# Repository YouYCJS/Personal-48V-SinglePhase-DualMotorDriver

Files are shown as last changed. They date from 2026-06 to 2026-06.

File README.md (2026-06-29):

# 48V Dual Motor Driver System (V2)
**48V 듀얼 모터 드라이버 시스템 — 컨트롤 + 파워 보드**

> ⚠️ Private — 직무 프로젝트 기록용

> 48V 환경에서 로터·스테이터를 구동하는 듀얼 모터 드라이버 시스템.
> PC 통신·전원 분배를 담당하는 ESP32 컨트롤 보드와, 게이트 드라이버·MOSFET로
> 실제 전류를 구동하는 파워 보드로 구성됩니다. (V1 → V2 스펙업 설계)

## 시스템 구성
PC ──USB──▶ [ESP32 컨트롤 보드] ──제어·전원──▶ [파워 보드] ──▶ 모터 (로터/스테이터)
---

# 1. ESP32 컨트롤 보드

PC와 통신해 제어 파라미터를 주고받고, 파워 보드로 제어 신호와 전원을 분배.

- **PC 인터페이스**: USB로 파라미터 입출력
- **전원 관리**: 12V → LM2596으로 5V 스텝다운, ESP32 공급
- **전원 분배**: 파워 보드로 12V / 3.3V 공급 (A89500 · ACS37220용)
- **전원 충돌 방지**: USB·외부전원 동시 인가 시 ESP32 손상 → 몰렉스 스위치로 전원 소스 택일

| 앞면 | 뒷면 |
|:---:|:---:|
| ESP32 보드 앞면 | ESP32 보드 뒷면 |

| 스키매틱 | PCB |
|:---:|:---:|
| ESP32 스키매틱 | ESP32 레이아웃 |

---

# 2. 파워 보드 (모터 컨트롤)

게이트 드라이버 + MOSFET로 실제 모터 전류를 구동. A/B상 풀브리지로 양방향 구동·전류 센싱.

### 구성
- **게이트 드라이버**: A89500 ×4
- **파워 MOSFET**: IRFB4115 ×8 (풀브리지)
- **전류 센서**: ACS37220 ×2 (위상별)
- **출력**: XT90 (A+/A-/B+/B-), 벌크 커패시터
- **기판**: 4-layer PCB

### 부품 선정 근거

V4 모터의 권선 저항(0.5~0.6Ω) 기준, 48V 구동 시 기동·인러시 구간에서 80~100A가 요구됨.
정상 운전 시 BEMF로 실 전류는 낮아지나, 최악 조건 대응을 위해 V1 대비 주요 부품을 스펙업.

**게이트 드라이버 — A89500 (Allegro)**
- 하프브리지 통합(HS+LS) + 부트스트랩 내장 → N채널만으로 H-브리지 구성
- 슛스루 방지 + 슈미트 트리거 입력 내장 → 기존 로직 게이트(SN74HCS14) 제거, BOM 간소화
- RESETn(FAULT)로 비상 정지 / 3.3V 로직 → ESP32-S3 직결
- *기존 1EDN8550(싱글 로우사이드, 하이사이드 외부회로 필요) 대비 통합도↑ 부품수↓ 안전성↑*

**파워 MOSFET — IRFB4115**

| 항목 | 기존 IRFZ44N | 신규 IRFB4115 |
|---|---|---|
| VDSS | 55V | **150V** (48V 대비 3배 마진) |
| ID | 49A | **104A** |
| RDS(on) | 17.5mΩ | **9.3mΩ** |
| Qg | 67nC | **150nC** |

- IRFZ44N은 내압 마진 1.15배뿐 → 역기전력 시 위험으로 48V 부적합
- IRFB4115로 마진 확보 + 저발열, 빠른 스위칭(A89500 조합)

**전류 센서 — ACS37220**

| 항목 | 기존 ACS712 | 신규 ACS37220 | 효과 |
|---|---|---|---|
| 측정 범위 | 최대 30A | **±150A** | 80~100A 측정 가능 |
| 발열(100A) | 12W | **1W** | 약 1/12 |
| ESP32 연결 | 5V→분압 필요 | **3.3V 직결** | 회로 간소화 |
| 과전류 보호 | SW(느림) | **HW FAULT 3µs** | 즉각 보호 |
| 응답 속도 | 80kHz | **150kHz** | PWM 측정 정확도↑ |

- ACS712는 80~100A 측정 자체 불가 → ACS37220으로 범위·발열·보호 모두 개선

### 설계 포인트
- **레이어 수 결정**: 6-layer 검토했으나 구조상 4-layer로 충분하다 판단 → 과설계·비용 배제
- **신호-전력 물리 분리**: 신호선을 PCB 트레이스로 라우팅하지 않고 점퍼선(하네스)으로
  컨트롤 보드-칩 직접 연결 → 파워부 노이즈 유입 물리적 차단, 디버깅·교체 유연성 확보
- **EMI 최소화**: 신호선이 파워 MOSFET부와 닿지 않도록 배선 최소화 + GND 가드링

### 완성된 보드

| 앞면 | 뒷면 |
|:---:|:---:|
| 파워 보드 앞면 | 파워 보드 뒷면 |

### 회로 설계
파워 보드 스키매틱

### PCB 레이아웃 (4-Layer)

| Layer 1 (Top) | Layer 2 |
|:---:|:---:|
| Layer 1 Top | Layer 2 |

| Layer 3 | Layer 4 (Bottom) |
|:---:|:---:|
| Layer 3 | Layer 4 Bottom |

---

## 설계 회고
- V1(BTS7960, 12V) → V2(A89500 + IRFB4115 + ACS37220, 48V) 스펙업 설계
- 부품 선정을 마진·발열·보호·통합도 기준으로 비교 검토 후 결정
- 제어(MCU)와 구동(파워)을 분리한 2-보드 시스템 아키텍처
- 고전류 환경의 노이즈를 4층 구조 + 하네스 분리 + GND 가드링으로 관리

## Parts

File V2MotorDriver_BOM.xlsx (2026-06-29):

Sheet: RotorStator_Control_Board(보드1개분
No, | 부품기호 | 갯수 | 값 | FOOTPRINT | 설명 | 공급처 | 단가 | 링크
1 | J1,J2,J5 | 3 | XT90PW-M | AMASS_XT90PW-M | 전원 커넥터, XT90PW 수, 2핀, 45A(연속)/피크90A, 500V, THT 수평실장 | 엘레파츠 | 1540 | https://www.eleparts.co.kr/goods/view?no=12773229
2 | D1 | 1 | SS54-HF | DIOM5025X220N | Diode, Schottky, 40V, 5A, SMA (DO-214AC) | 디바이스마트 | 1331 | https://www.devicemart.co.kr/goods/view?no=15948320
3 | D2 | 1 | SMCJ58A | DIOM7959X262N | TVS Diode, Unidirectional, 58V Standoff, 93.6V Clamp, 1500W, SMC (DO-214AB) | 디바이스마트 | 1331 | https://www.devicemart.co.kr/goods/view?no=15930384
4 | R1,R3,R4,R5,R7,R8 | 6 | 10K | RES0805W | ChipResistor, SMD, F급, (±1%), 10K옴, 2012, 1/8W | 디바이스마트 | 5.5 | https://www.devicemart.co.kr/goods/view?no=1376585
5 | R2,R6 | 2 | 66.5K | RES0805W | ChipResistor / SMD / F급 / (±1%) / 66.5K옴 / 2012 사이즈 / 1릴 : 5000개 | 디바이스마트 | 2.97 | https://www.devicemart.co.kr/goods/view?no=26630
6 | C1,C4 | 2 | 470uF | CAPAE1900X2200N | 470uF ±20% 100V Aluminum Electrolytic Capacitors 5000hrs@105℃ | 디바이스마트 | 12221 | https://www.devicemart.co.kr/goods/view?no=16012986
7 | M1,M2,M3,M4, M5,M6,M7,M8 | 8 | IRFB4115 | IRFB4115 | INFINEON - IRFB4115PBF - Power MOSFET, N Channel, 150 V, 104 A, 0.011 ohm, TO-220AB, Through Hol | 디바이스마트 | 6127 | https://www.devicemart.co.kr/goods/view?no=14931375
8 | C2,C5,C6,C9,C11,C14,C16,C17,C20,C22 | 10 | 100nF(=0.1uF) | CAP0805R | 2012 / 100nF / 50V / K급 / SMD세라믹캐패시터 | 디바이스마트 | 44 | https://www.devicemart.co.kr/goods/view?no=8191
9 | C3,C10,C15,C21 | 4 | 1uF | CAP0805R | 사이즈 : 2012 / 전압 : 50Vdc / 용량 : 1uF / 오차 : ±10 % / 온도특성 : X7R | 디바이스마트 | 88 | https://www.devicemart.co.kr/goods/view?no=14913274
10 | C7,C12,C18,C23 | 4 | 10uF | CAP0805R | 사이즈 : 2012 / 전압 : 25Vdc / 용량 : 10uF / 오차 : ±10 % / 온도특성 : X5R | 디바이스마트 | 88 | https://www.devicemart.co.kr/goods/view?no=14913258
11 | C8,C13,C19,C24 | 4 | 470nF(=0.47uF) | CAP0805R | 2012 / 470nF / 50V / K급 / SMD세라믹캐패시터 | 디바이스마트 | 17.6 | https://www.devicemart.co.kr/goods/view?no=1382403
12 | FL1,FL2 | 2 | BLM18AG601SN1D | BEADC1608X95N | 페라이트 비드 600 OHM 25% Alternate Sizing Guide Below / Mouser Part Number : 81-BLM11A601S | 디바이스마트 | 187 | https://www.devicemart.co.kr/goods/view?no=15405006
13 | J3 | 1 | S10B-XH-A | JST_B10B-XH-A | Connector Header Through Hole, Right Angle 10 position 0.098" (2.50mm) / Digi-Key Part Number : 455-S10B-XH-A-ND | 디바이스마트 | 990 | https://www.devicemart.co.kr/goods/view?no=15442721
14 | A1,A2 | 2 | ACS37220LEZATR-150B3 ACS37220LEZATR-100B3 | ACS37220 | Current Sensor, Hall-Effect, ±150A, Bidirectional, 3.3V, Analog Out, QFN-7 (4x4mm) Current Sensor, Hall-Effect, ±100A, Bidirectional, 3.3V, Analog Out, QFN-7 (4x4mm) | 디바이스마트 | 5269 | https://www.devicemart.co.kr/goods/view?no=16042461
15 | U1,U2,U3,U4 | 4 | A89500GEJTR-T | A89500GEJTR-T | Gate Driver, Half-Bridge, 100V, N-Ch MOSFET, Bootstrap, 8-15V VCC, DFN-10 | 디바이스마트 | 3003 | https://www.devicemart.co.kr/goods/view?no=16042465
16 | J4 | 1 | 35318-0420 | MOLEX_353180420 | Connector, Header, Mini-Fit Jr, 4.2mm, 2x2, 4-Circuit, Right-Angle, 6A, THT | 디바이스마트 | 814 | https://www.devicemart.co.kr/goods/view?no=16042466

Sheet: ESPBoard
No, | 부품기호 | 갯수 | 값 | FOOTPRINT | 설명 | 공급처 | 단가 | 링크
1 | C2 | 1 | 100uF | 100uF | [SAMYOUNG] SMD E/C 35V 100uF (105℃)/6.3 Ø x8mm | 디바이스마트 | 220 | https://www.devicemart.co.kr/goods/view?no=30362
2 | DG5,DG6 | 2 | 141V (6핀) | 141V-6P | 핀간격 2.54mm / 전압 150V / 전류 2A / AWG : 26~20 | 디바이스마트 | 1243 | https://www.devicemart.co.kr/goods/view?no=23323
3 | DG2,DG3 | 2 | 141V (12핀) | 141V-12P | 핀간격 2.54mm / 전압 150V / 전류 2A / AWG : 26~20 | 디바이스마트 | 2475 | https://www.devicemart.co.kr/goods/view?no=23317
4 | DG1 | 1 | 141V (20핀) | 141V-20P | 핀간격 2.54mm / 전압 150V / 전류 2A / AWG : 26~20 | 디바이스마트 | 4125 | https://www.devicemart.co.kr/goods/view?no=23309
5 | C1 | 1 | 220uF | 220uF | [SAMYOUNG] SMD E/C 35V 220uF (85℃)/8Ø x10mm | 디바이스마트 | 198 | https://www.devicemart.co.kr/goods/view?no=1245625
6 | J1,J5 | 2 | 39288040 | 5566-02_MOL | 5557 커넥터에 사용 / 스트레이트 타입 / 4.2mm 피치 / 2pin | 디바이스마트 | 319 | https://www.devicemart.co.kr/goods/view?no=348
7 | J2,J6 | 2 | 39288040 | 5566-04_MOL | 5557 커넥터에 사용 / 스트레이트 타입 / 4.2mm 피치 / 4pin | 디바이스마트 | 385 | https://www.devicemart.co.kr/goods/view?no=349
8 | C3 | 1 | 100nF(=0.1uF) | CAP0805R | 2012 / 100nF / 50V / K급 / SMD세라믹캐패시터 | 디바이스마트 | 44 | https://www.devicemart.co.kr/goods/view?no=8191
9 | D1 | 1 | SS34 | DIOM7959X265N | SMD타입 3A/40V, 서지 100A (4.5X2.5) / SMA | 디바이스마트 | 110 | https://www.devicemart.co.kr/goods/view?no=11738
10 | U2 | 2 | ESP32-S3-WROOM2 | ESP32-S3-DEVKITC-1 | 핀헤더 소켓 / 스트레이트 타입 / DIP 타입 / 2.54mm pitch / 1열 / 40pin | 디바이스마트 | 583 | https://www.devicemart.co.kr/goods/view?no=3585
11 | J3,J4 | 2 | S10B-XH-A | JST_B10B-XH-A | Connector Header Through Hole, Right Angle 10 position 0.098" (2.50mm) / Digi-Key Part Number : 455-S10B-XH-A-ND | 디바이스마트 | 990 | https://www.devicemart.co.kr/goods/view?no=15442721
12 | R1 | 1 | 1K | RES0805W | ChipResistor / SMD / J급 / (±5%) / 1K옴 / 2012 | 디바이스마트 | 5.5 | https://www.devicemart.co.kr/goods/view?no=19277
13 | R2 | 1 | 3.3K | RES0805W | ChipResistor / SMD / B급 / (±0.1%) / 3.3K옴 / 2012 / HighPrecisionChipResistors / 1/10W / 온도계수(TCR=25ppm) | 디바이스마트 | 253 | https://www.devicemart.co.kr/goods/view?no=39586
14 | L1 | 1 | 33uH | SC1280S-33uH | 파워인덕터 / 용량값 : 33uH / 사이즈 : 12.2 X 12.2 X 8.0/ -20℃ ~85℃ | 디바이스마트 | 242 | https://www.devicemart.co.kr/goods/view?no=6615
15 | VR1 | 1 | LM2596S-5.0 | VREG_LM2596S-5.0/NOPB | Buck Switching Regulator IC Positive Fixed 5V 1 Output 3A TO-263-6, D2PAK (5 Leads + Tab), TO-263BA / Digi-Key Part Number : LM2596S-5.0/NOPB-ND | 디바이스마트 | 14982 | https://www.devicemart.co.kr/goods/view?no=12458270

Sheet: Sheet1
3 | 1485 | 4455 |  | 1 | 220 | 220
1 | 1331 | 1331 |  | 2 | 1243 | 2486
1 | 1331 | 1331 |  | 2 | 2475 | 4950
6 | 5.5 | 33 |  | 1 | 4125 | 4125
2 | 2.97 | 5.94 |  | 1 | 198 | 198
2 | 12221 | 24442 |  | 2 | 319 | 638
8 | 6127 | 49016 |  | 2 | 385 | 770
10 | 44 | 440 |  | 1 | 44 | 44
4 | 88 | 352 |  | 1 | 110 | 110
4 | 88 | 352 |  | 2 | 583 | 1166
4 | 17.6 | 70.4 |  | 2 | 990 | 1980
2 | 187 | 374 |  | 1 | 5.5 | 5.5
1 | 990 | 990 |  | 1 | 253 | 253
2 | 5269 | 10538 |  | 1 | 242 | 242
4 | 3003 | 12012 |  | 1 | 14982 | 14982
1 | 814 | 814 |  |  |  | 32169.5
 |  | 106556.34 |  |  |  |  | 02+
 |  |  | 852450.72 | 257356
 |  |  |  | 1269806.72

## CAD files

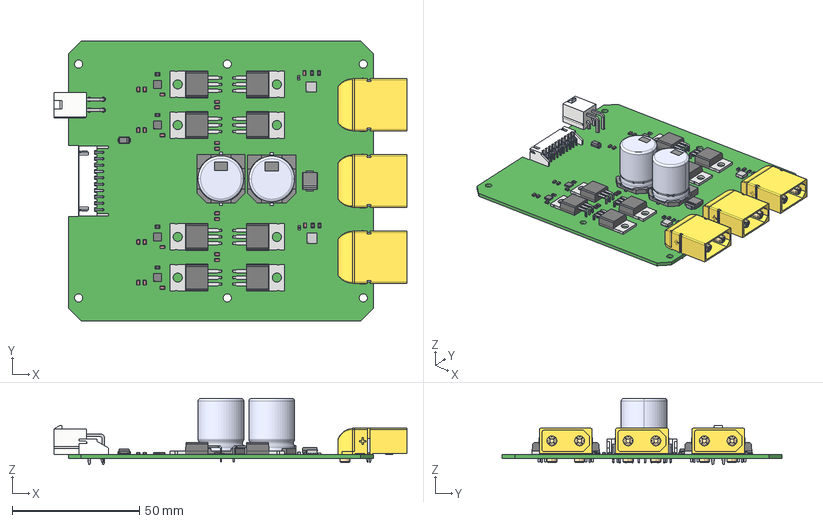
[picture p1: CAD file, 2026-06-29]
48V-MotorDriver-DualControlBRD/RotorStator_PowerControl.step
138.9 x 110.0 x 26.0 mm
FILTER_BLM18AG_MUR x 2
RES0805 x 8
TO-220_horizontal_line x 8
SxB-XH-A_10
pin^SxB-XH-A ass_bent x 2
pin^SxB-XH-A ass x 8
ACS37220 x 2

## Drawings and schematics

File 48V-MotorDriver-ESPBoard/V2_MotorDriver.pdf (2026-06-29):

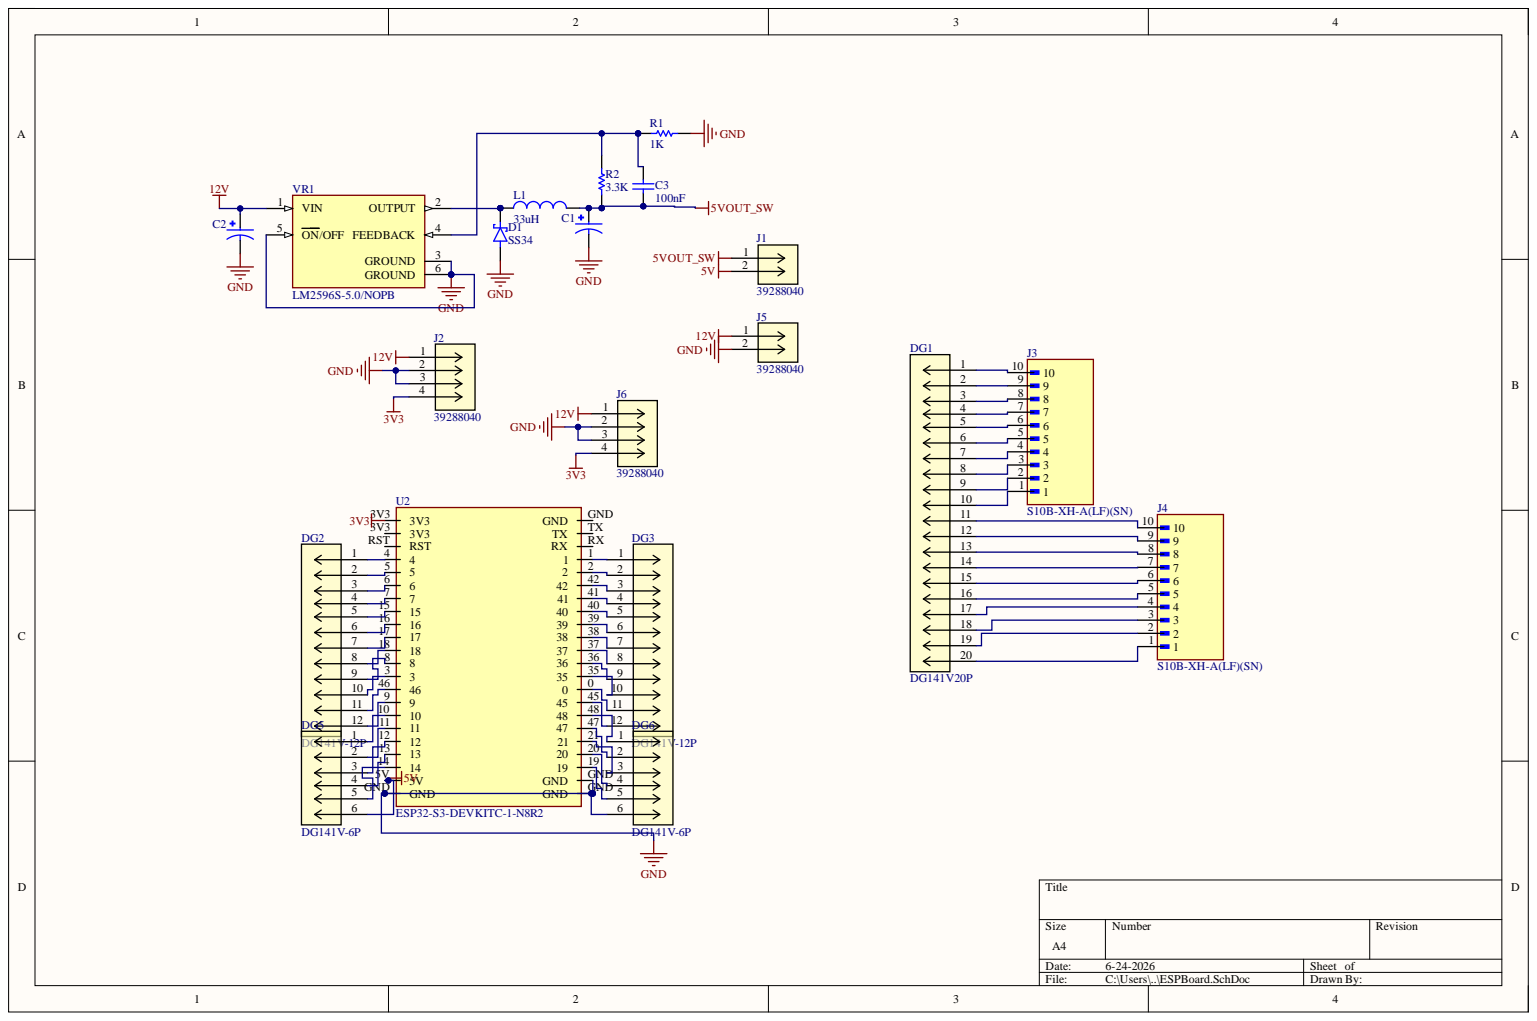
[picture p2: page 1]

RST RST 4 4 5 5 6 6 7 7 15 15 16 16 17 17 18 18 8 8 3 3 46 46 9 9 10 10 11 11 3V3 3V3 12 12 13 13 14 14 5V 5V GND GND

1 0
1 1
1 | D G 6

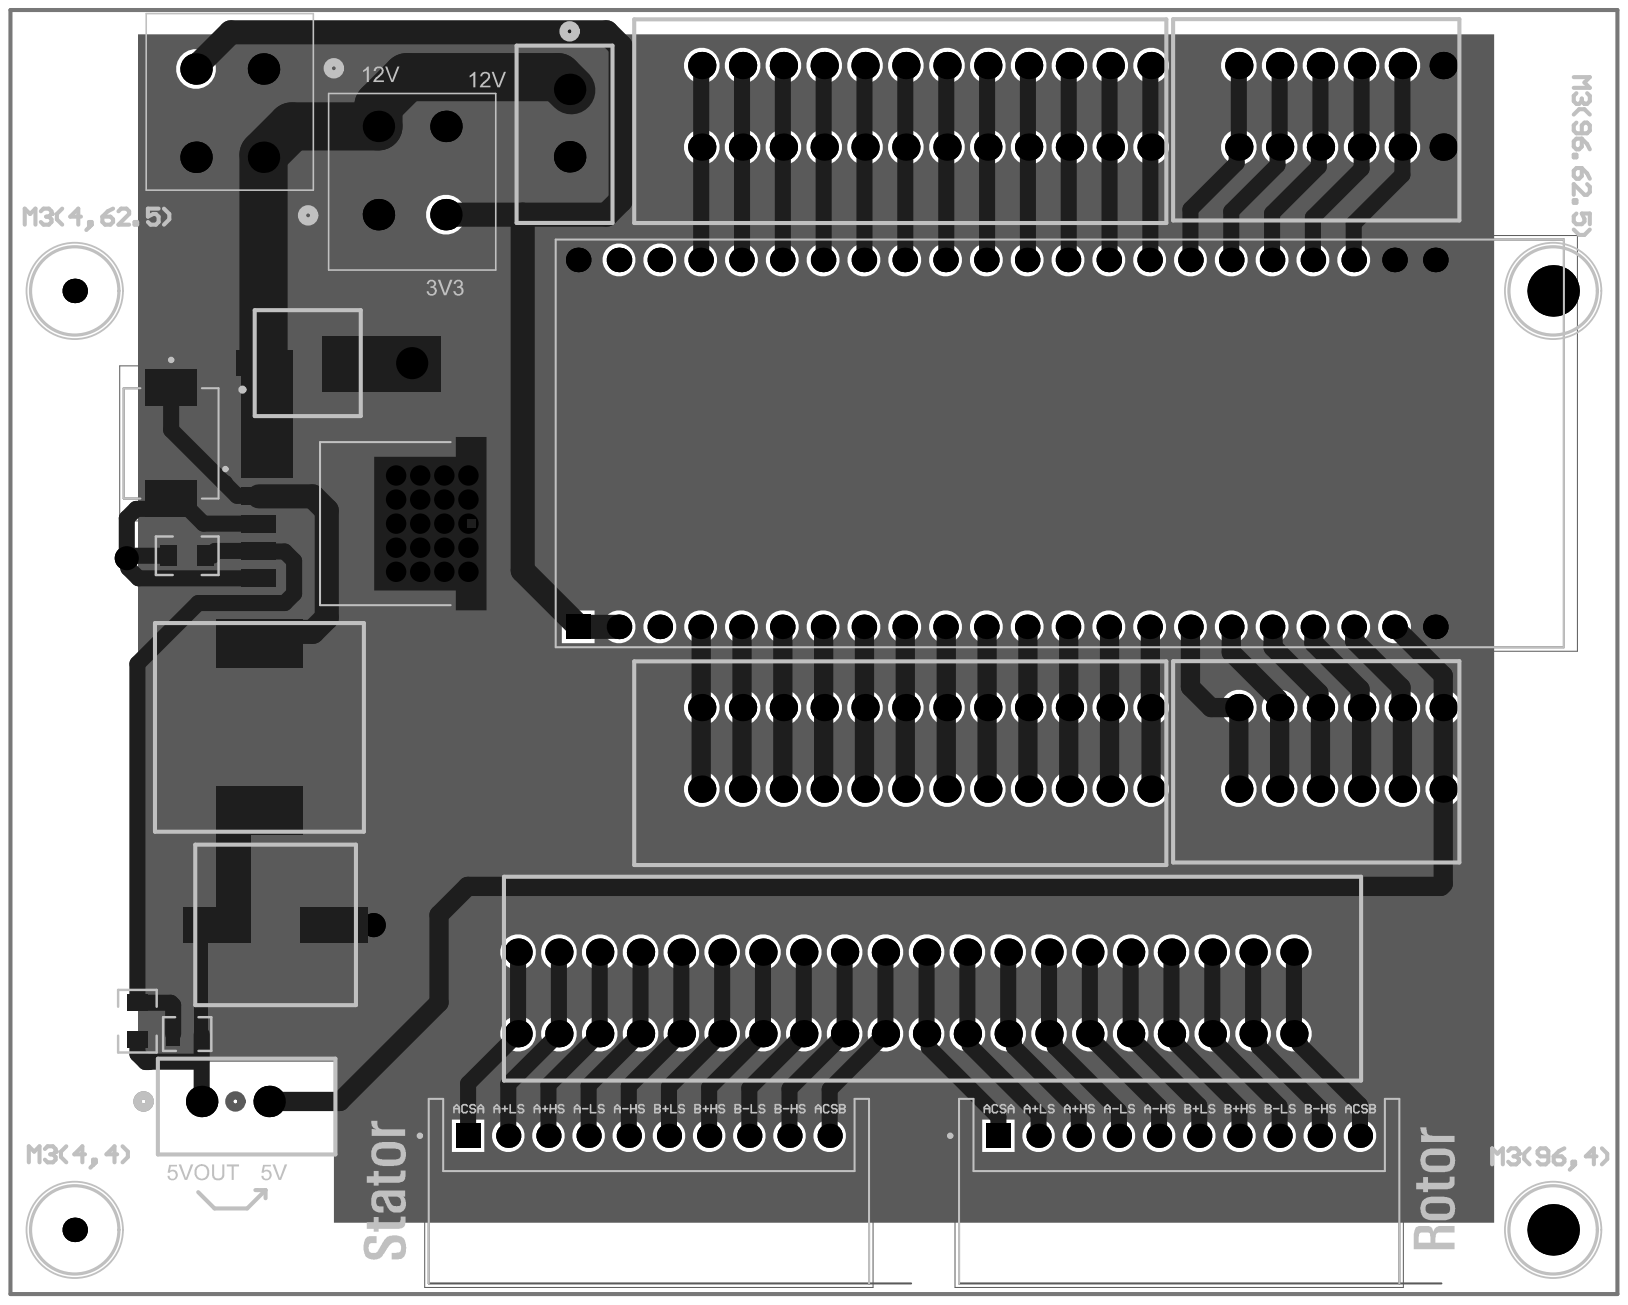
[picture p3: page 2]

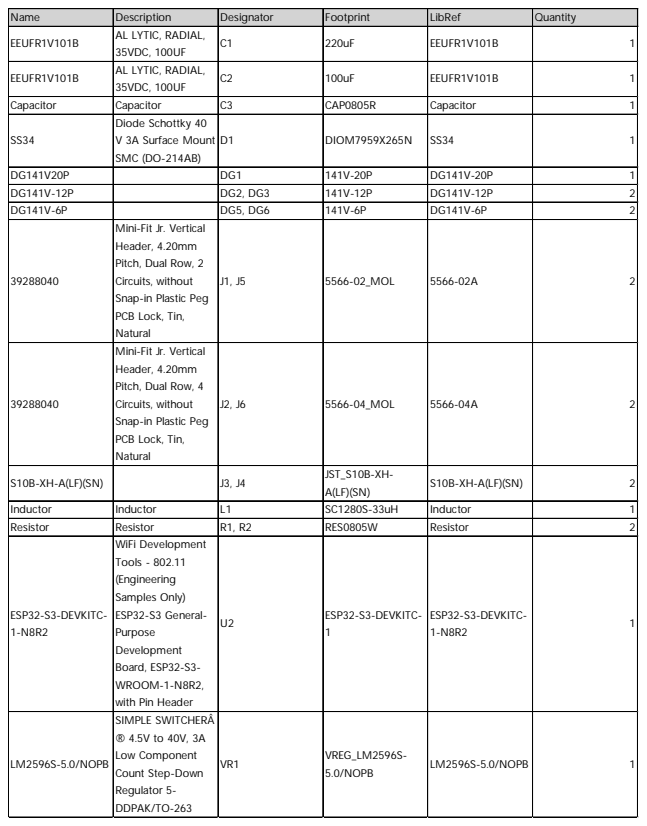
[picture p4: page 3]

Name | Description | Designator | Footprint | LibRef | Quantity
EEUFR1V101B | AL LYTIC, RADIAL, 35VDC, 100UF | C1 | 220uF | EEUFR1V101B | 1

EEUFR1V101B | AL LYTIC, RADIAL, 35VDC, 100UF | C2 | 100uF | EEUFR1V101B | 1

Capacitor | Capacitor | C3 | CAP0805R | Capacitor | 1
SS34 | Diode Schottky 40 V 3A Surface Mount SMC (DO-214AB) | D1 | DIOM7959X265N | SS34 | 1

DG141V20P | | DG1 | 141V-20P | DG141V-20P | 1
DG141V-12P | | DG2, DG3 | 141V-12P | DG141V-12P | 2
DG141V-6P | | DG5, DG6 | 141V-6P | DG141V-6P | 2
39288040 | Mini-Fit Jr. Vertical Header, 4.20mm Pitch, Dual Row, 2 Circuits, without Snap-in Plastic Peg PCB Lock, Tin, Natural | J1, J5 | 5566-02_MOL | 5566-02A | 2

39288040 | Mini-Fit Jr. Vertical Header, 4.20mm Pitch, Dual Row, 4 Circuits, without Snap-in Plastic Peg PCB Lock, Tin, Natural | J2, J6 | 5566-04_MOL | 5566-04A | 2

S10B-XH-A(LF)(SN) | | J3, J4 | JST_S10B-XH-A(LF)(SN) | S10B-XH-A(LF)(SN) | 2

Inductor | Inductor | L1 | SC1280S-33uH | Inductor | 1
Resistor | Resistor | R1, R2 | RES0805W | Resistor | 2
ESP32-S3-DEVKITC-1-N8R2 | WiFi Development Tools - 802.11 (Engineering Samples Only) ESP32-S3 General-Purpose Development Board, ESP32-S3-WROOM-1-N8R2, with Pin Header | U2 | ESP32-S3-DEVKITC-1 | ESP32-S3-DEVKITC-1-N8R2 | 1

LM2596S-5.0/NOPB | SIMPLE SWITCHERÂ ® 4.5V to 40V, 3A Low Component Count Step-Down Regulator 5-DDPAK/TO-263 | VR1 | VREG_LM2596S-5.0/NOPB | LM2596S-5.0/NOPB | 1
